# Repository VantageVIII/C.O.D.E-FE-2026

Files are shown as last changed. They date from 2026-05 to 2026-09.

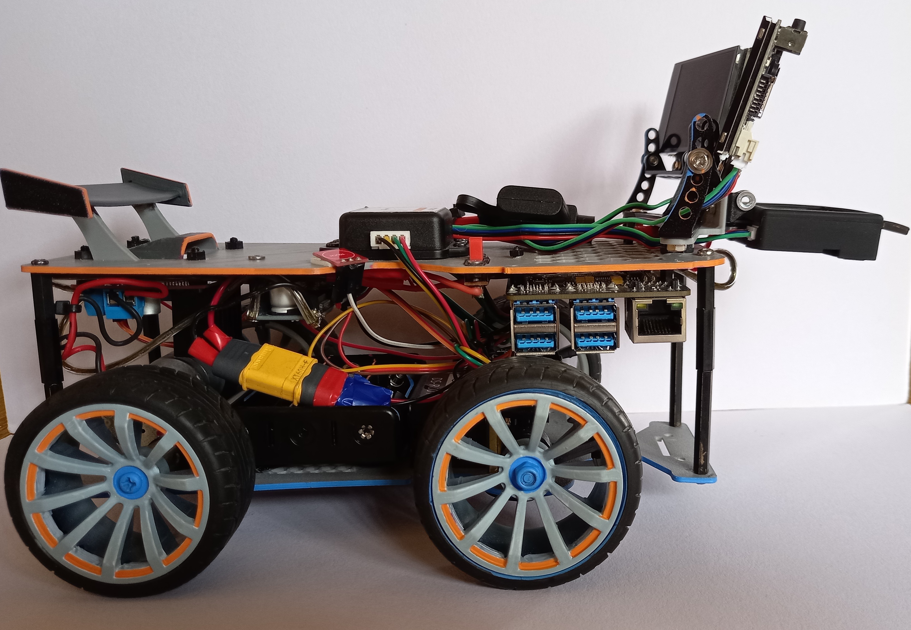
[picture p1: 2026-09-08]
media/Robot photos/Right.jpg

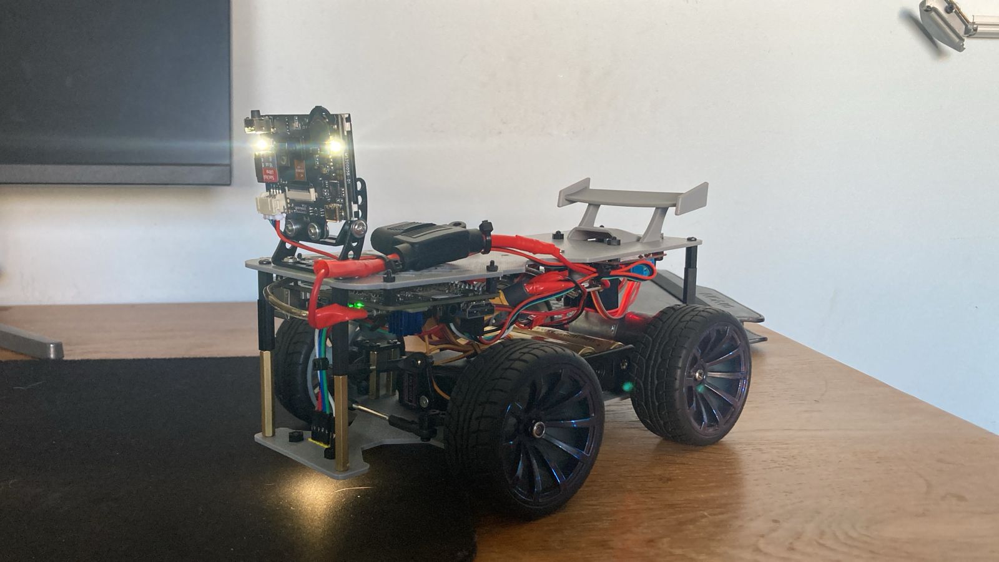
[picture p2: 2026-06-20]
media/Additional Media/Photos/WhatsApp Image 2026-05-23 at 15.05.25.jpeg

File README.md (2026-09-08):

# Team C.O.D.E. - WRO Future Engineers 2026

**Team Name:** Cognitive Operations & Digital Engineering (C.O.D.E.)

**Team Members:** Jadon Steele & Mischa Miller

**Robot Name:** MSE-6 (Alias: "Mouse")

Welcome to the official GitHub repository for Team C.O.D.E. This repository contains all the source code, 3D CAD models, documentation, and media for our autonomous vehicle designed for the World Robot Olympiad (WRO) Future Engineers 2026 competition. 

Our engineering philosophy this season focuses on **simplification and consistency**. By upgrading to an RDK X5 edge computer and a tri-camera HuskyLens vision system, we shifted the complexity from hardware sensor arrays to software processing, resulting in a highly reliable, reproducible autonomous system.

---

## 1. Repository Structure

Our repository is organized to ensure full reproducibility for any team wishing to recreate the MSE-6:

* `/Codes/`: Contains all software required to run the robot.
  * `/Base Codes/`: Contains low-level hardware interfacing scripts (e.g., pin definitions, bit-bashing logic, motor controller initialization).
  * `/Main Codes/`: Contains the high-level logic, including the finite state machine, mapping algorithms, and obstacle avoidance logic for the competition runs.
  * `/Test Codes/`: Contains isolated scripts used during development to test individual components.
* `/models/`: Contains all 3D-printable `.STL` files for our custom ABS chassis, including the upper plate, lower plate, ribs, and camera mounting brackets.
* `/Documentation/`: Contains our Engineering Journal, component comparisons, color value logs, and problem-solving logs.
* `/media/`: Contains photos and videos of the robot in action, including official qualification run recordings.
* `/other/`: Contains reference materials, rulebooks, and legacy code from the 2025 season for comparative analysis.

---

## 2. Electromechanical Components & Hardware Architecture

The MSE-6 is built using carefully selected commercial off-the-shelf components combined with a custom-fabricated chassis.

### Main Controller
* **RDK X5 SBC:** The brain of our robot. Featuring an octa-core ARM Cortex-A55 processor, 8 GB of LPDDR4 memory, and a 10 TOPS NPU (Neural Processing Unit). We selected the RDK X5 over alternatives because of its superior AI capabilities, which are essential for processing three simultaneous camera feeds. 

### Vision & Sensor System
* **3x HuskyLens V1 AI Cameras:** We utilize a tri-camera setup. One camera faces downward to read mat colors. Two forward-facing cameras are angled to provide a combined 120° field of view, detecting track boundaries and traffic pillars without blind spots.
* **DFRobot 6-Axis Accelerometer/Gyro:** Mounted precisely on the chassis center axis. This provides crucial heading data to maintain perfectly straight trajectories between turns.

### Actuation & Movement
* **Drive Motor:** A 12V 250 RPM Planetary DC motor. We opted for a high-torque ratio rather than a high-speed ratio. Because our code relies on GPIO bit-bashing for motor control, a torque-oriented layout allows for much smoother, less twitchy movement.
* **Steering:** A DFRobot DS-R001 6Kg Clutch Servo. The internal clutch mechanism is a critical reliability upgrade—if the robot collides with a wall, the clutch slips instead of stripping the servo gears.
* **Motor Driver:** L298N Dual H-Bridge.

### Power System
* **Battery:** 3S1P 18650 Lithium-ion pack (11.1V nominal). 
* **Power Regulation:** The 11.1V line runs into an XL4015 Buck Converter which steps the voltage down to a stable 5V. From the buck converter, the 5V line passes through a **5A inline blade fuse** before routing to the RDK X5 and logic components. This specific topology ensures that our 5V circuit is strictly protected from drawing more than the buck converter's maximum rating if a short occurs.

---

## 3. Step-by-Step Build & Assembly Guide

### Mechanical Assembly
1. **Print the Chassis:** Navigate to the `/models/` directory and 3D print the upper and lower chassis plates using ABS filament. ABS is required due to the operating temperatures of the RDK X5.
2. **Mount the Drivetrain:** Secure the 12V Planetary DC motor to the rear motor bracket of the lower chassis. Attach the rear solid axle and wheels.
3. **Install the Steering System:** Mount the DFRobot 6Kg Clutch Servo to the front of the lower chassis. Connect the steering linkage to the front hubs.
4. **Assemble the Tiers:** Use the provided nylon spacers to mount the upper chassis plate above the lower plate.
5. **Mount the Sensors:** Attach the custom 3-camera bracket to the upper chassis. Angle the forward cameras outwards at 15° each from the center line. 

### Electrical Wiring & Integration

Wiring Diagram

1. **Power Routing:** Connect the 3S1P battery to the XL4015 Buck Converter. Route the 5V output of the buck converter through the 5A inline fuse.
2. **Logic Power:** Connect the output of the 5A fuse to the RDK X5 power input pins. Route a parallel 12V line directly from the battery to the L298N motor driver.
3. **Motor Control:** Connect the RDK X5 GPIO pins to the IN1, IN2, and ENA pins on the L298N. 
4. **Sensor Comms:** Connect the three HuskyLens cameras and the DFRobot Gyro to the I2C/UART interface pins on the RDK X5. 

---

## 4. Software Architecture & Game Strategy

Our software is written in Python and runs on the RDK OS. We utilize a highly optimized Finite State Machine (FSM) to separate our strategies for Round 1 (Open Challenge) and Round 2 (Obstacle Challenge).

### Round 1: Open Challenge Strategy

[View Round 1 Flowchart (PDF)](./Documentation/flowcharts/Round%201%20Flowchart.pdf)

In Round 1, there are no traffic pillars, so our goal is maximum speed and efficiency.
1. **Orientation Logic:** The downward-facing camera scans the mat to identify the starting color (blue or orange), determining if the robot must travel clockwise or counterclockwise.
2. **Heading & Execution:** The robot relies entirely on the DFRobot Gyro for its heading. It is programmed to hug the **outer wall** as closely as possible, allowing for a wider turning radius and maximizing our top speed while remaining stable.

### Round 2: Obstacle Challenge Strategy

[View Round 2 Flowchart (PDF)](./Documentation/flowcharts/Round%202%20Flowchart.pdf)

In Round 2, the robot must obey the red and green traffic pillars. To guarantee reliability, we split the logic between a "Mapping Lap" and "Execution Laps".
1. **Orientation Logic:** Similar to Round 1, the downward camera sets the initial orientation.
2. **Lap 1 (Corner Mapping & Evaluation):** The robot drives forward using gyro heading. Crucially, the robot is programmed to **stop** at the start of a corner turn. It uses the forward-facing HuskyLens to evaluate the traffic pillar situated at the corner. Based on the pillar's color and the robot's current orientation (CW/CCW), the algorithm determines if it needs to execute a **"narrow"** or **"sharp"** turn.
3. **Memory Storage:** The robot saves this specific corner turn type (narrow or sharp) into an array sequence.
4. **Laps 2 & 3 (Corner Execution & Real-Time Avoidance):** For the remaining two laps, the robot utilizes a hybrid approach:
   * **Corner Turns (Memory):** When the robot reaches the corners, it does not rely on the cameras. Instead, it reads the saved turn sequence (narrow or sharp) from memory and executes it "blindly." This is a vital engineering decision: by navigating corners purely from memory on Laps 2 and 3, the robot mitigates the risk of missing a pillar or executing a wrong turn due to minor offsets or imperfections that accumulate over the run.
   * **Straightaway Pillars (Real-Time):** For pillars located on the straight sides of the track, the robot actively uses the forward HuskyLens cameras to detect and avoid them in real-time, safely shifting lanes as necessary.

---

## 5. Installation & Execution Guide

### To run the software on a fresh RDK X5 setup:
**Application Download List:**
* [RDK Studio](https://d-robotics.github.io/rdk_x_doc/en/RDK/)
* [Thonny](https://thonny.org/)
* [Github Desktop](https://desktop.github.com/download/)
* [Google Antigravity](https://antigravity.google/download)

1. **Flash the OS:** Download the official RDK Studio and flash RDK OS Linux onto the RDK X5.

2. **Install Dependencies:** Ensure Python 3 is installed. Then install the required libraries:
   ```bash
   pip install matplotlib numpy smbus smbus2
   sudo apt-get install i2c-tools
   ```

3. **Clone the Repository:**
   ```bash
   git clone https://github.com/VantageVIII/C.O.D.E-FE-2026.git
   cd C.O.D.E-FE-2026
   ```

4. **Run the Code:** Navigate to the Main Codes directory and execute the competition script:
   ```bash
   cd Codes/Main\ Codes/
   python3 main_run.py
   ```

---

## 6. License and Credits
Designed and programmed by Team C.O.D.E. (Jadon Steele & Mischa Miller) for the WRO Future Engineers 2026 Season. Special thanks to HelderBerg Robotics Club for their continued support, and Prints by Paul for 3D manufacturing assistance.

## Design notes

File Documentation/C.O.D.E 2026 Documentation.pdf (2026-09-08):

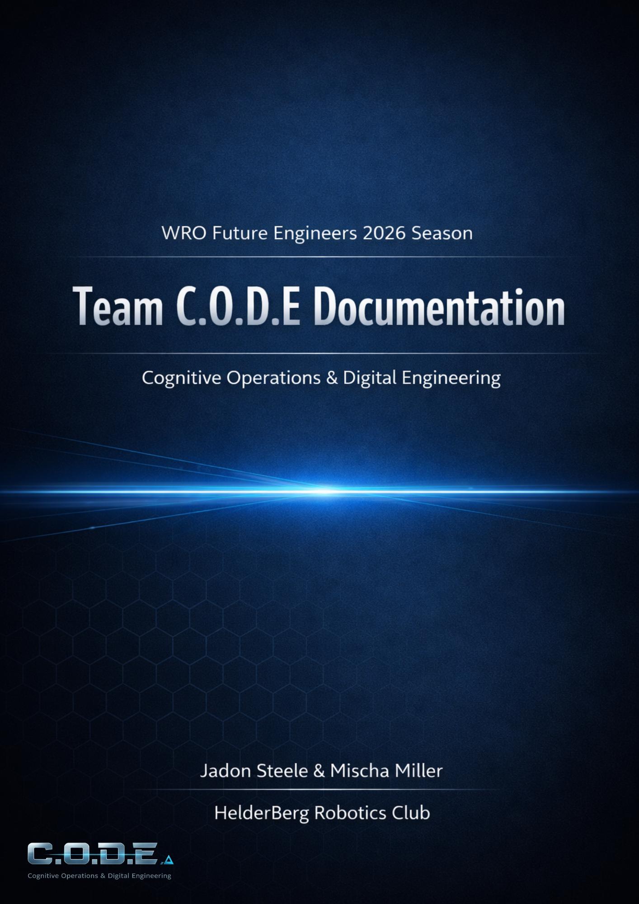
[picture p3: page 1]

# Index

### 1 Introduction

### 1.1 Team Introduction

### 1.2 Robot Introduction

### 2 Robot Hardware

### 2.1 Interfaces

### 2.1.1 UART

### 2.1.2 I2C

### 2.2 Electronics

### 2.2.1 RDK X5

- Libraries
- Reason

### 2.2.2 Power

- Batteries
- Blade 5A Fuse & Fuse Holder
- Buck Converter

### 2.2.3 Sensors

- Huskylens V1
- Gyro (DFRobot 6-Axis Accelerometer)
- Capacitive Touch Sensor

### 2.2.4 Movement

- DS-R001 – Clutch Servo Motor
- DC Motor
- L298N

### 2.2.5 Wiring Diagram

### 2.3 Chassis/Other

### 3 Software and Strategy

### 3.1 Open challenge Strategy

### 3.2 Obstacle challenge Strategy

### 3.3 Calibration

### 3.4 Open challenge flowchart

### 3.5 Obstacle challenge flowchart

### 4 Robot Journey

### 4.1 Changes from 2025 Season

### 4.2 Monthly Logs

- January Log
- February Log
- March Log
- April Log
- May Log
- June Log
- July Log
- August Log

# Team Introduction: Team C.O.D.E

We are Team C.O.D.E, (https://github.com/VantageVIII/C.O.D.E-FE-2026.git) a two-person team competing in the WRO Future Engineers category. We first met during last season's FTC competition and quickly discovered that we shared a passion for robotics, engineering, and programming. Since then, we've worked together to design, build, and improve an autonomous vehicle that can tackle the challenges of the Future Engineers competition.

## Meet the Team:

### Mischa Miller

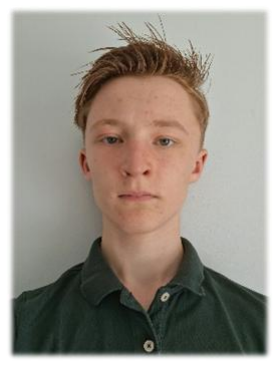
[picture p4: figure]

Role: Strategy & Quality Assurance Lead

Mischa is responsible for planning, testing, and keeping the project organised. He manages our engineering journal, tracks our progress, and helps make sure every change we make is tested and documented. His focus is on making sure the team stays on schedule and that our robot performs consistently and reliably.

### Jadon Steele

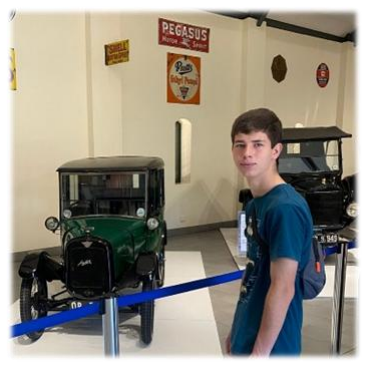
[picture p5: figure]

Role: Lead Engineer & Programmer

Jadon leads the design and development of our robot. He is responsible for programming the autonomous system, integrating sensors, and improving the mechanical design. Drawing on several years of robotics competition experience, he enjoys solving technical problems and finding ways to make our robot more accurate and reliable.

## Our Goal:

Our goal is to represent South Africa for the WRO International Finals. To get there, we're focused on building a reliable autonomous vehicle that can consistently complete every challenge in the Future Engineers competition. We know that success comes through careful planning, regular testing, and continuously improving our design. No matter the result, we hope to learn new skills, gain valuable experience, and represent our team to the best of our ability.

# Robot Introduction

Meet the WRO FE MSE-6 (also known as Mouse), our autonomous vehicle designed specifically for the WRO Future Engineers competition. Every component was selected to maximise reliability, performance, and consistency during autonomous operation.

The robot uses a tri-camera HuskyLens AI setup. Two cameras face forward, each with a 60° field of view, giving wide coverage of the competition field. A third camera faces downward toward the mat, replacing the original colour sensor.

- Forward cameras:
- Detect lane markings, pillars, and obstacles.
- Provide a combined forward view that improves navigation accuracy and reduces blind spots.
- Downward camera:
- Captures mat colours and features with greater precision than the previous colour sensor.
- Operates at higher speed, enabling faster runs without sacrificing detection reliability.
- Supplies data for mapping and route planning, feeding into the robot’s ID set → route set pipeline.

Advantages of the Tri-Camera System

- Higher accuracy: Downward HuskyLens delivers richer colour and pattern recognition.
- Speed optimisation: Robot maintains faster lap times while keeping detection consistent.
- Consistency: Reduces twitching and misreads, ensuring smoother lap execution.

Processing the large amount of data from the cameras requires a powerful onboard computer. For this reason, we chose the RDK X5, which features an octa-core ARM Cortex-A55 processor and 8 GB of LPDDR4 memory. This provides enough computing power to run our vision algorithms and control systems in real time, allowing the robot to operate fully autonomously.

The following sections describe the robot's mechanical design, electronics, software, and the testing process that led to the final version of the MSE-6.

For the Mechanical, electronic, and software design we tried to keep it as simple as possible

# Robot Photos:

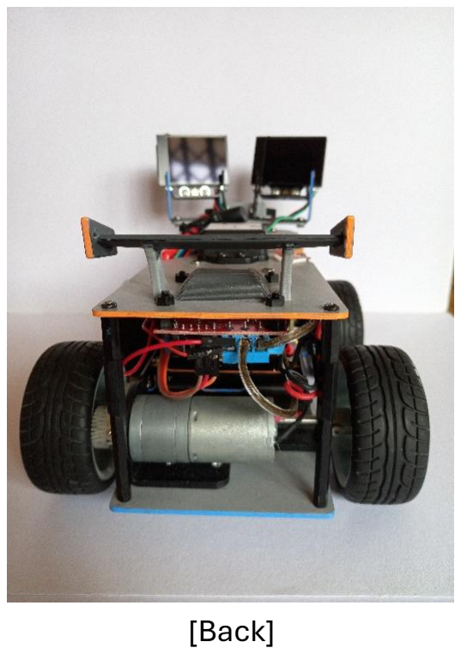
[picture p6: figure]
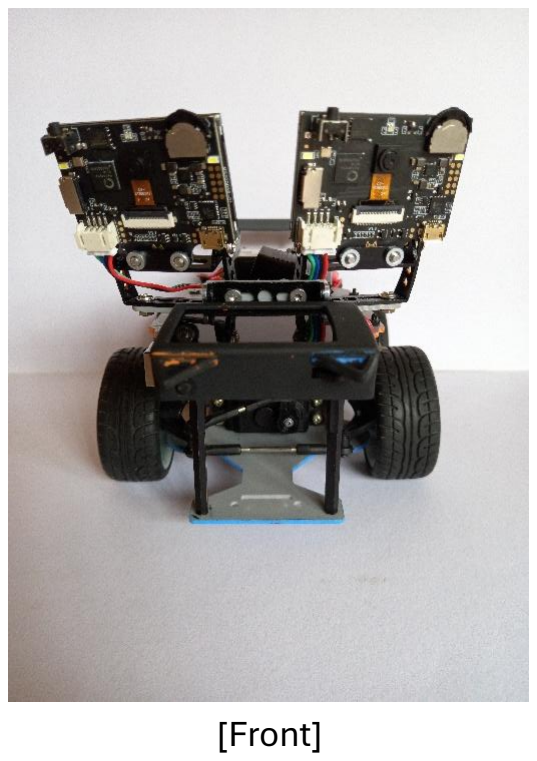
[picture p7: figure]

[Front] | [Back]

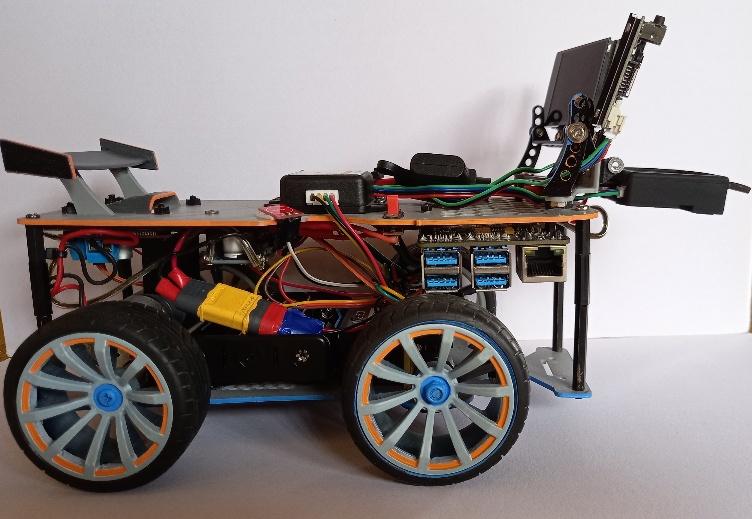
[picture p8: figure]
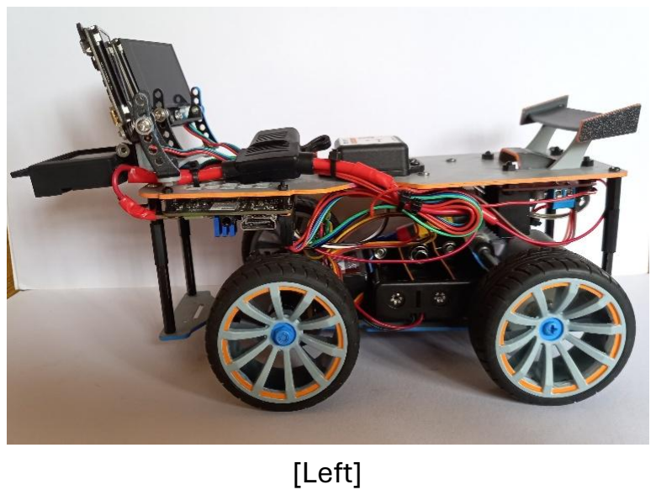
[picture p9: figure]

[Right] | [Left]

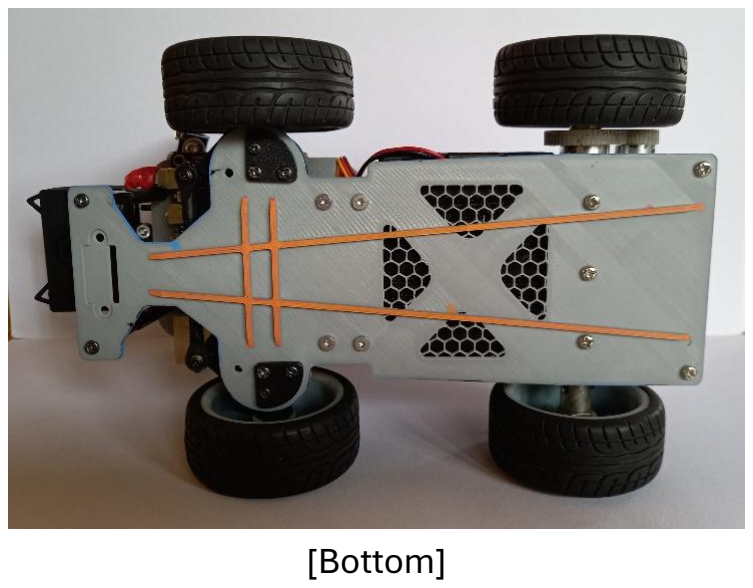
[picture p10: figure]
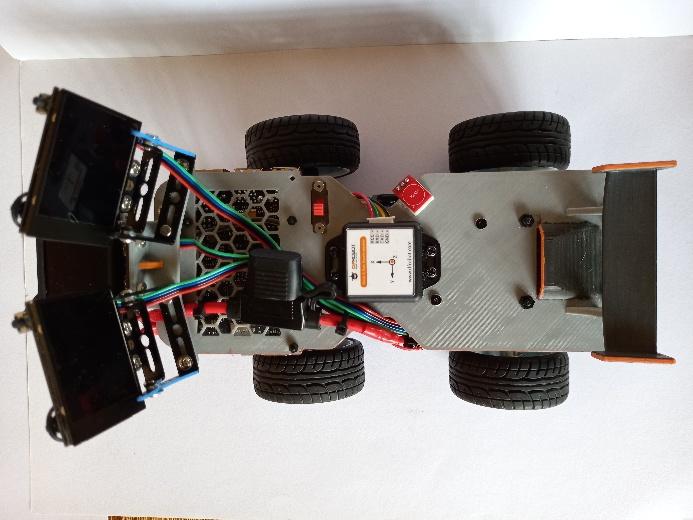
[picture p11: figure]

[Bottom] [Top]

# Robot Hardware/Specifications:

## Interfaces:

### UART:

Universal Asynchronous Receiver/Transmitter (UART)
Definition:

UART is a hardware communication protocol that enables asynchronous serial data transmission between devices. It converts parallel data from a microcontroller or computer into serial form for transmission and reconverts received serial data back into parallel form.

Key Characteristics:

- Asynchronous Communication: No shared clock signal; synchronization is achieved using start and stop bits.
- Full Duplex: Supports simultaneous transmission (TX) and reception (RX).
- Frame Structure: Data is sent in packets consisting of: • Start bit (signals beginning of data frame) • Data bits (usually 7, 8, or 9 bits) • Optional parity bit (error detection) • Stop bit(s) (signals end of frame)
Typical Parameters:
- Baud Rate: Speed of transmission (e.g., 9600, 115200 bps).
- Data Bits: Commonly 8 bits per frame.
- Parity: None, even, or odd.
- Stop Bits: 1 or 2 bits.
Applications:
- Microcontroller ↔ Sensor communication (e.g., accelerometers, GPS modules).
- Debugging and logging via serial consoles.
- Embedded systems interfacing (Arduino, Raspberry Pi, etc.).
- Peripheral connections (Bluetooth modules, GSM modems).

Hardware Interface:

- TX (Transmit): Sends data out.
- RX (Receive): Reads incoming data.
- GND: Common ground reference.
- Optional RTS/CTS lines for hardware flow control. Advantages:
- Simple and widely supported.
- Requires only two data lines (TX, RX).
- Flexible baud rate configuration.
Limitations:
- Point-to-point only (not multi-drop like RS-485).
- Limited distance and speed compared to modern protocols (e.g., USB, SPI).
- No inherent clock synchronization — requires precise baud rate matching. Components Using UART:
- 3x HUSKYLENS V1
- Gyro
_________________________________________________________________________________

I2C:

Inter-Integrated Circuit (I²C)
Definition:

I²C is a synchronous, multi-master, multi-slave, serial communication protocol developed by Philips (now NXP). It enables short-distance communication between integrated circuits using only two bidirectional lines: SDA (Serial Data) and SCL (Serial Clock).

Key Characteristics:

- Synchronous Communication: Data transfer is synchronized with a shared clock (SCL).
- Two-Wire Interface: Only SDA and SCL lines are required, plus ground.
- Multi-Device Support: Multiple masters and slaves can share the same bus.
- Addressing: Each slave device has a unique 7-bit or 10-bit address.
- Open-Drain Design: Devices pull the line low; external pull-up resistors are required. Typical Parameters:
- Clock Speed: Standard (100 kHz), Fast (400 kHz), Fast Plus (1 MHz), High-Speed (3.4 MHz).
- Data Frame Structure: • Start condition (SDA pulled low while SCL is high) • Address frame (7/10 bits + R/W bit) • ACK/NACK bit (acknowledgment from receiver) • Data frames (8 bits each, followed by ACK/NACK) • Stop condition (SDA released high while SCL is high)
Applications:
- Communication between microcontrollers and peripherals (EEPROMs, sensors, displays).
- Configuration of ICs in embedded systems.
- Power management ICs and real-time clocks.
- Consumer electronics (smartphones, TVs, cameras). Hardware Interface:
- SDA (Serial Data): Transfers data between devices.
- SCL (Serial Clock): Synchronizes data transfer.
- Pull-Up Resistors: Required on both lines to maintain logic high when idle.

Advantages:

- Simple wiring (two lines for many devices).
- Supports multiple masters and slaves.
- Well-suited for low-speed, short-distance communication. Limitations:
- Limited speed compared to SPI or UART.
- Bus capacitance restricts maximum distance and number of devices.
- Requires careful pull-up resistor sizing for reliable operation. Components Using I²C:
- TCS34725 – Colour Sensor (Removed)

### ______________________________________________________________________

## Electronics:

### RDK X5:

The RDK X5 was chosen as the main controller for the robot because it offers the best balance of AI acceleration, connectivity, and GPIO support compared to other SBCs in the comparison:
AI Acceleration:
- Equipped with a 10 TOPS BPU (Neural Processing Unit), the RDK X5 is far more capable for edge AI and robotics tasks than the Raspberry Pi 5 (limited AI acceleration) and Jetson Nano (fixed 4 GB RAM, older GPU).
Connectivity:
- Built-in Wi-Fi 6 + Bluetooth 5.4 ensures modern wireless standards, unlike the Jetson Nano which lacks onboard Wi-Fi.
GPIO & Interfaces:
- Provides 28 GPIOs with support for SPI, I²C, I²S, PWM, and UART, covering all the communication protocols needed for sensors and actuators in the robot.
Form Factor:
- Compact dimensions (85 × 56 × 20 mm) make it stackable and ideal for embedded robotics, unlike the larger Jetson Nano or LattePanda Delta 3.

Power Input:
- Runs on a simple 5V/5A USB-C supply, compatible with the robot’s buck converter and battery system.
OS Support:
- Supports Ubuntu 22.04 and RDK OS Linux, giving flexibility for robotics frameworks like ROS2.
Why Not the Others?
- Raspberry Pi 5: Excellent community support and dual 4K display, but limited AI acceleration and requires active cooling.
- Jetson Nano: Strong AI features with CUDA, but restricted by fixed 4 GB RAM and no onboard Wi-Fi.
- LattePanda Delta 3: Runs Windows/Linux with powerful x86 CPU, but higher power draw and larger form factor make it less suited for compact robotics.
Conclusion:
The RDK X5 was selected because it combines AI performance, modern connectivity, versatile GPIO support, and compact design, making it the most suitable SBC for an edge AI robotics platform.
_________________________________________________________________________________

### Power:

Battery System – 18650 Lithium Cells (3S1P Pack)

Configuration
- Type: 18650 Lithium-ion cells
- Arrangement: 3S1P (3 cells in series, 1 parallel string)
- Nominal Voltage per Cell: 3.7 V
- Capacity per Cell: ~3000 mAh (3.0 Ah)
Pack Specifications
- Nominal Voltage: Vtotal = 3 × 3.7 V = 11.1 V
- Maximum Voltage (Fully Charged): Vmax = 3 × 4.2 V = 12.6 V
- Total Capacity: Ctotal = 3.0 Ah
- Energy Stored: E = 11.1 V × 3.0 Ah ≈ 33.3 Wh

Current Output
- Continuous Current: Depends on the discharge rating of the cells. • Standard 18650 cells: ~5–10 A continuous • High-drain 18650 cells (used in power tools, e-bikes, robotics): 15–20 A continuous, sometimes higher
- Peak Current: Short bursts can exceed 20 A depending on cell quality.
- Pack Limitation: Since this is a 3S1P pack, the current capability is limited to what a single cell can provide (no parallel strings to share load).
Practical Notes
- Runtime per pack: ~45 minutes under typical robot load.
- Multiple packs are rotated to ensure a fully charged set is always available.
- Inline 5 A fuse in combination with the Buck Converter is used for protection of the board, but the cells themselves can deliver much higher current. _________________________________________________________________________________________ Buck Converter – 5V/5A (XL4015)

Part Description
The XL4015 is used to step down our 11.1V battery to a stable 5V to safely power the RDK X5 and HuskyLenses. We specifically required a regulator with a 5A limit because our combined AI processing and vision system draws a peak of ~4.19A. We chose this switching buck converter over a linear regulator because of its high conversion efficiency (up to 96%), ensuring that power isn't wasted as heat during our 3-lap runs.
Quick Specifications
- Input Voltage: 4 – 38 V
- Output Voltage: 1.25 – 32 V (adjustable)
- Output Current: 5 A (max; recommended ≤ 4.5 A)
- Output Power: 75 W
- Working Temperature: –40 to +85 °C
- Working Frequency: 180 kHz
- Conversion Efficiency: up to 96% (depends on input/output voltage, current, and voltage drop)
- Load Regulation Rate: S(I) ≤ 0.8%
- Voltage Adjustment Rate: S(U) ≤ 0.8%
- Protection: Short-circuit protection, Over-temperature protection
- Dimensions: 54 × 23 × 18 mm
- Net Weight: 13 g

Fuse – 5A Blade Type

Part Description
The 5A blade fuse is a critical safety mechanism for our robot's logic circuit. We installed it directly after the XL4015 Buck Converter on the 5V line before the power reaches the RDK X5 and HuskyLenses. We explicitly chose a 5A rating because our peak logic current draw is calculated at ~4.19A. This provides enough headroom for AI processing spikes, but guarantees that if a short circuit occurs, the fuse will blow before our sensitive logic components melt or the buck converter exceeds its maximum rating.
Quick Specifications
- Rated Voltage: 32 V
- Rated Current: 5 A
- Fuse Colour: Clear Orange
- Dimensions: 19 × 19 × 5 mm
- Net Weight: 13 g

Fuse Holder – Inline Blade Type
Part Description
This inline holder integrates the 5A blade fuse into our main wiring harness. We chose an inline automotive-style holder because it provides a highly secure, vibration-proof connection during high-speed runs and sharp 45° turns. Furthermore, its simple plug-and-play design means that if we blow a fuse during a competition round, we can physically replace it in the pits in under 10 seconds without needing to solder or rewire the chassis.
Quick Specifications
- Max Voltage: 48 V
- Max Current Rating: 32 A (Peak 40 A)
- Fuse Seat Size: 40 × 35 × 24 mm
- Net Weight: 23 g

### Sensors:

Huskylens V1 – AI Vision Sensor:
Part Description

The HuskyLens is the core of our robot's vision system. We transitioned from a 2025 sensor array (Time-of-Flight + traditional colour sensors) to a custom Tri-Camera HuskyLens setup. One camera faces downward for high-speed mat colour recognition (track mapping), while two face forward, angled to provide a massive 120° combined field of view to detect traffic pillars on corners. We chose the HuskyLens specifically to offload processing from our main computer. Instead of the RDK X5 analysing raw video pixels, the built-in Kendryte K210 AI chip on the HuskyLens handles the heavy object-recognition math, sending only lightweight coordinate data to the RDK X5 via I2C/UART. This brilliant division of labour drops our system latency and drastically improves lap times.
Quick Specifications
- Processor: Kendryte K210
- Image Sensor: OV2640 (2.0 Megapixel Camera)
- Supply Voltage: 3.3 – 5.0 V
- Current Consumption (Typical): 320 mA @ 3.3 V, 230 mA @ 5.0 V (face recognition mode; 80% backlight brightness; fill light off)
- Connection Interface: UART, I²C
- Display: 2.0-inch IPS screen, 320 × 240 resolution
- Built-in Algorithms: Face Recognition, Object Tracking, Object Recognition, Line Tracking, Colour Recognition, Tag Recognition
- Dimensions: 52 × 44.5 mm

Gyro – DFRobot 6 axis accelerometer:
Part Description

The gyro is the cornerstone of our robot's straight-line navigation. In Round 1, the robot relies entirely on this sensor's heading data to hug the outer wall of the track at high speeds. We specifically selected this DFRobot module over cheaper alternatives (like the standard MPU6050) because it features an integrated microprocessor running advanced Kalman filter algorithms. This means the sensor internally cleans up its own noise and calculates an accurate attitude angle before sending data to the RDK X5. By offloading this math, we save valuable CPU cycles on the RDK X5 for processing our three camera streams. During testing, we applied a deliberate 10° software offset to the gyro's zero-heading, which biases the robot slightly inward during runs to prevent accidental outer-wall clipping.

Quick Spec

- Voltage: 3.3V~5V
- Current: <40mA
- Measuring Dimension: acceleration: 3D; angular velocity: 3D; attitude angle: 3D
- Range: acceleration: ±2/4/8/16g(optional); angular velocity: ±250/500/1000/2000°/s (Optional); attitude angle: ±180°
- Dimensions: 51.3 x 36 x 10mm
- Net Weight: 18g

TTP223 Capacitive Touch Sensor:
Part Description

The WRO rulebook requires a strict, physical start procedure to initiate the autonomous run. We utilize the TTP223 as our main start trigger. We chose a capacitive touch sensor over a traditional mechanical push-button to solve a critical software issue: "signal bounce." Mechanical switches physically bounce when pressed, sending dozens of rapid ON/OFF signals in a matter of milliseconds, which can accidentally multi-trigger or crash our software's bit-bashing loop. The TTP223 IC completely eliminates this issue, delivering a single, digitally clean, and debounced signal that guarantees a flawless launch off the starting line every single time. Quick Spec

- IC: TTP223 Touch Pad Detector
- Input Voltage: 2.0V – 5.5V DC
- Standby Current: < 10µA
- Response Time: ~60ms (Fast Mode) / ~220ms (Low Power Mode @3V)
- Touch Detection Range: 0 – 10mm (depending on surface material)
- Output Modes: Momentary or Latching / Active-High or Active-Low selectable
- Sensitivity Adjustment: External capacitance (0–50pF)
- Auto Calibration: Recalibrates every 4 seconds (no touch)
- Operating Temperature: –40°C to +85°C
- Dimensions: 15mm × 11mm × 2.5mm

### Movement

DS-R001 – 6Kg Clutch Servo Motor:
Part Description

This servo acts as our front-wheel steering actuator. We upgraded to this clutch servo after our original MG996R burned out during testing. The built-in clutch mechanism is vital for our robot's reliability: if the robot crashes into a track wall, the clutch slips at 6kg of torque rather than stripping the internal gears or stressing our 3D-printed chassis linkage. This gives us much smoother and safer steering.
Quick Spec
- Operating Voltage: 4.8-6V DC
- Static Current: ≤10mA @ 6.0V
- Current (at no load): ≤60mA @6.0V
- Current (at stopped): ≤1.65A @6.0V
- Rated Torque: ≥4.4kg·cm @6.0V
- Stall Torque: 6kg.cm @6.0V
- Operating Travel: 300°±10°
- Pulse Width Range: 500~2500μs
- Communication Mode: PWM

L298N – Dual H-Bridge Motor Driver:
Part Description

The L298N serves as the critical link between our RDK X5 logic controller and our 12V drive motor. Unlike our sensors which run off the 5V buck converter, the L298N is wired directly to the 11.1V battery line to provide maximum unchecked voltage to the drivetrain. We chose this specific H-Bridge because of its massive onboard heat sink and high power-dissipation rating (25W). Because we use a software "bit-bashing" control method rather than hardware PWM, the control signals sent to the driver's ENA pin can cause rapid switching states; the L298N's robust thermal design easily absorbs the resulting heat without failing during long competition rounds

Quick Spec

- Dual H-Bridge Driver
- IC: L298N (ST),/li>
- Logic voltage: 5VDC (has onboard 5V regulator if you would like to power from 12V)
- Drive voltage: 5-35VDC
- Drive current: 2A (MAX single bridge)
- Dimensions: 43 x 57mm

DC Motor – 250 RPM Planetary
Part Description
This planetary DC motor powers our solid-axle rear-wheel drive. Selecting the right motor was one of our most important design trade-offs. We intentionally avoided high-speed motors in favour of this torque-oriented 250 RPM model. Because our RDK X5 utilizes bit-bashing for motor control, a highly geared, torque-heavy motor allows for much smoother and more predictable acceleration, eliminating the sudden "twitching" we experienced with faster motors. Additionally, its stall torque of 3.86 kg.cm easily overcomes the static friction and inertia of our fully loaded chassis, while the internal metal planetary gears prevent the transmission from stripping during emergency braking or rapid direction changes.
Quick Spec
- Operating Voltage: 12V (6-18V range)
- Current (no load): 100mA
- Current (load): 330mA
- Stall Current: 1500mA
- Speed (no load @ 12V): 250rpm
- Speed (load @ 12V): 175rpm
- Load Torque: 1.1kg.cm (0.107 Nm)
- Stall Torque: 3.86kg.cm (0.378 Nm)
- Gear Ratio: 1:35
- Shaft Length: 8mm
- Shaft Diameter: 4mm
- Shaft Style: D-Shape
- Dimensions: 52.6 x 24.4mm (diameter)
- Weight: 87g

### Wiring Diagram

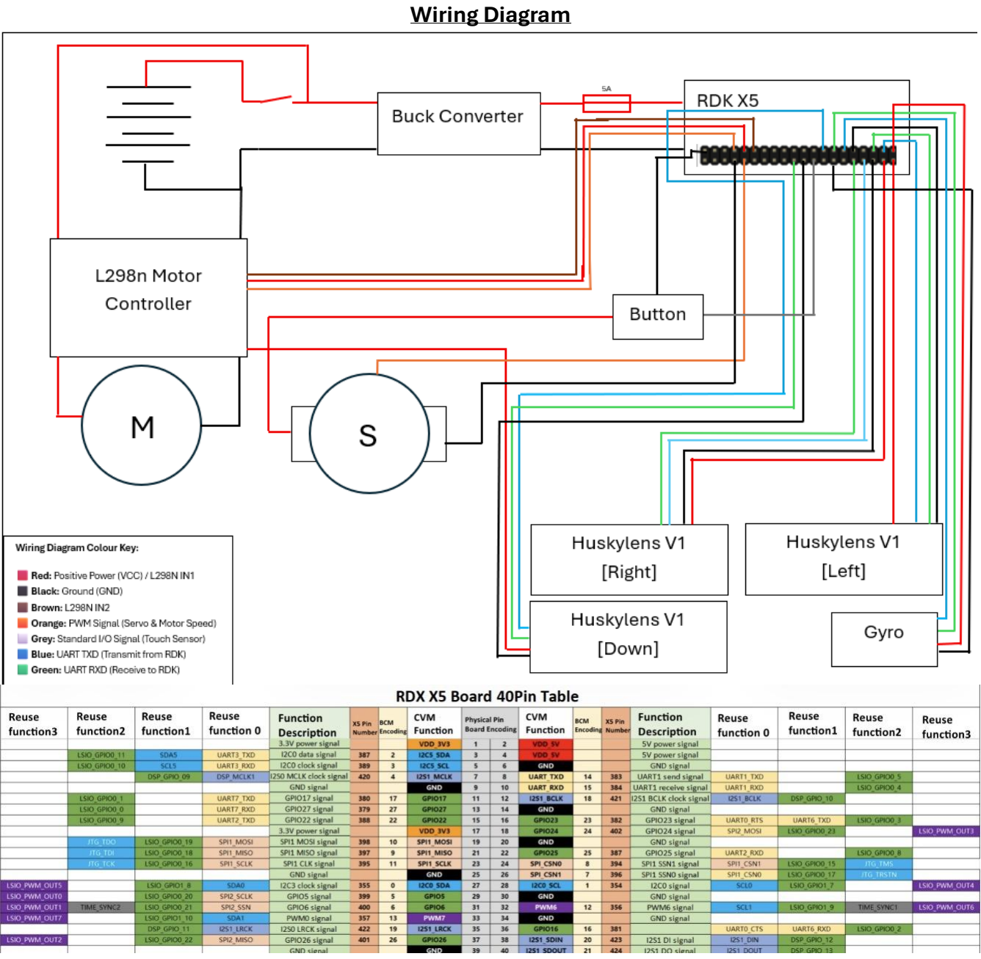
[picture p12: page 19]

## Chassis/Other

Our chassis is primarily 3D-printed from Creality ABS filament, manufactured by Prints by Paul. ABS was selected over PLA or PETG because of its thermal resistance and rigidity — ensuring the frame does not flex under load and can withstand the heat generated by the RDK X5 SBC and the L298N H-Bridge motor controller.
Material Choices
- ABS (Chassis plates):
- High rigidity prevents flexing under torque.
- Superior thermal tolerance compared to PLA, reducing risk of warping near heat-intensive components.
- Metal (Motor brackets):
- Supplied with the starter kit.
- Used where motors apply direct mechanical load, ensuring durability and preventing bracket deformation.
Structural Design
- Two-plate layout:
- Plates separated by spacers for modularity and airflow.
- Lower chassis: houses the servo motor, DC motor, and battery pack.
- Upper chassis: houses the RDK X5, L298N motor controller, 5A buck converter, 3x Huskylens V1 camera, capacitive touch sensor (button), and DFRobot 6-axis gyro.
- Rib reinforcement:
- Bottom chassis includes ribs to distribute stress and resist cracking.
- Provides additional strength against torque forces from the DC motor and steering servo.
- Airflow optimization:
- Designed with channels and spacing to direct airflow to thermal-intensive components.
- Prevents overheating during extended runs.

Drivetrain & Geometry:

- Configuration: Solid-axle rear-wheel drive, with front-wheel steering.
- Wheelbase: 115 mm (11.5 cm).
- Steering angle: Up to 50°, yielding a 40 cm turning radius.
- Wheel dimensions: 25 mm width, 65 mm diameter.
- Track width: 140 mm overall.

Functional & Aesthetic Features:

- Air scoop: positioned to “cool” the motor controller, while also adding a distinctive look.
- Wing handle: doubles as a carrying grip, especially useful during runaway test moments.
- Personal touches: break away from the typical cube-like or brick-like robot designs, giving the chassis personality and recognizability.

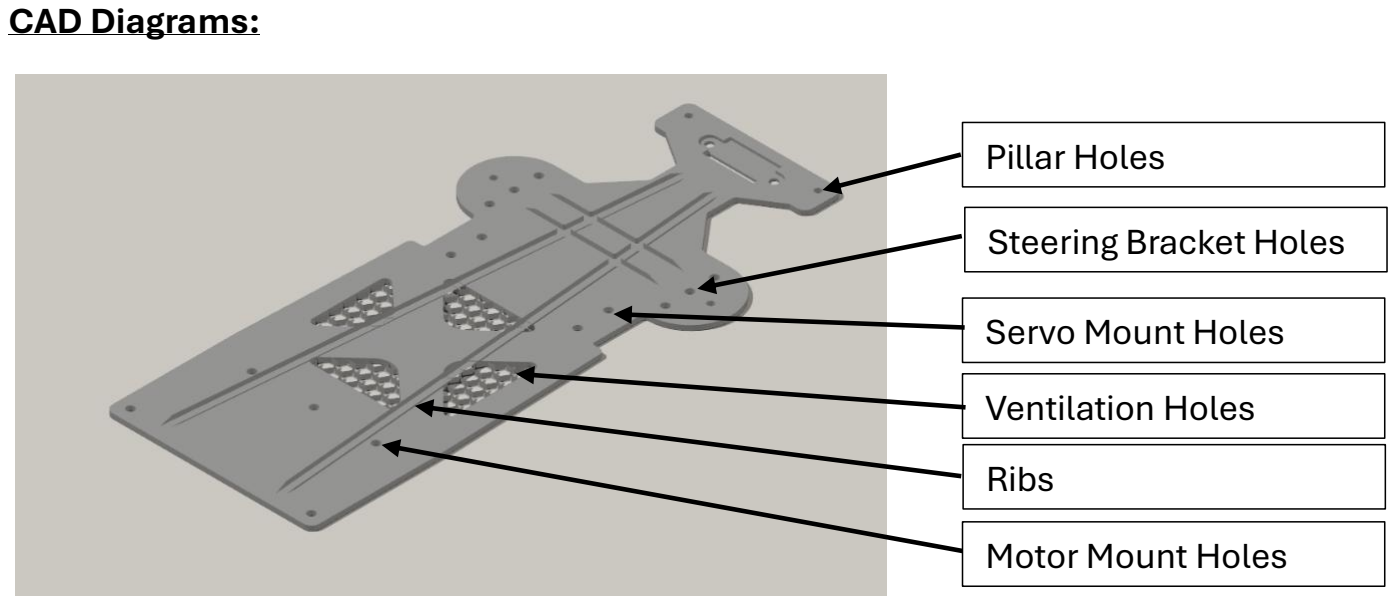
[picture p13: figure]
CAD Diagrams:; Ribs; Steering Bracket Holes; Ventilation Holes; Pillar Holes; Motor Mount Holes; Servo Mount Holes
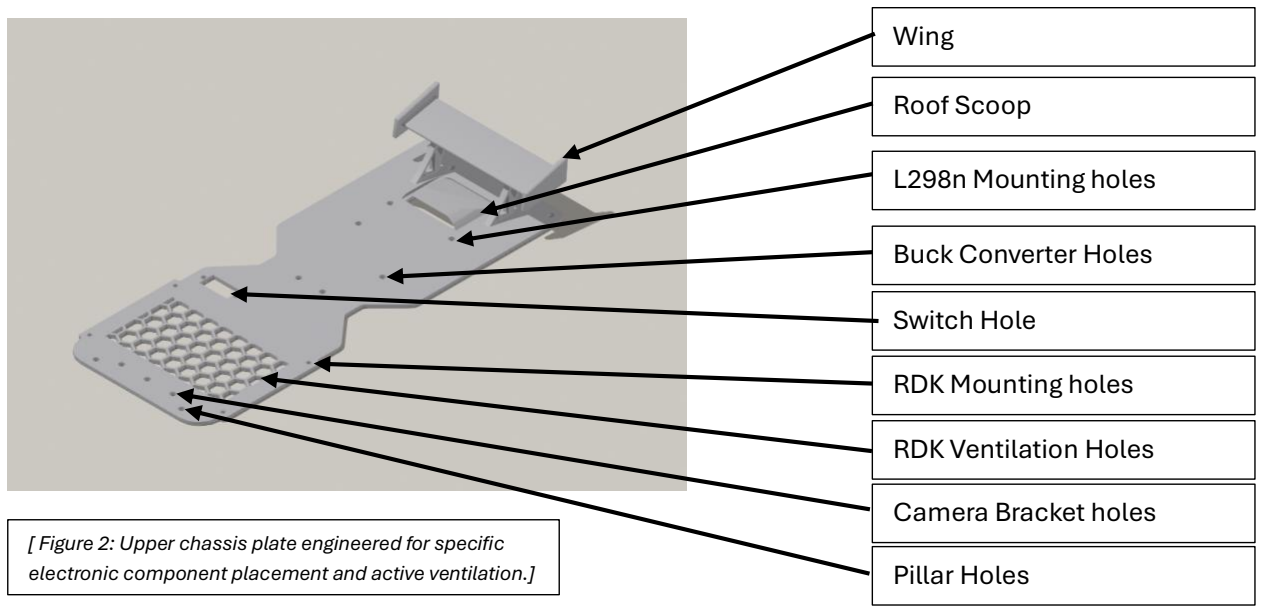
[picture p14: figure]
Pillar Holes; RDK Mounting holes; Buck Converter Holes; L298n Mounting holes; Wing; RDK Ventilation Holes; Camera Bracket holes; Roof Scoop; Switch Hole

Camera mounting holes

[ Figure 2: Upper chassis plate engineered for specific electronic component placement and active ventilation.]

[Figure 1: Lower chassis plate highlighting longitudinal structural ribs and motor mounts.]

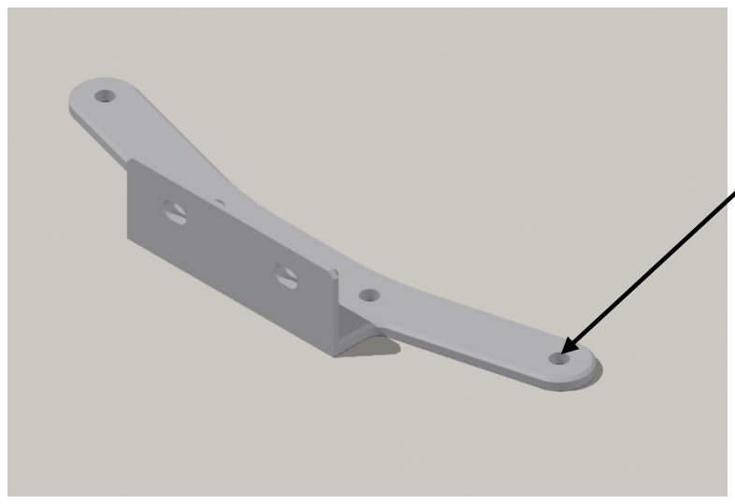
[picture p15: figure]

[Figure 3: Custom tri-camera HuskyLens mounting bracket.]

# Software & Strategy

### Round 1: Open Challenge Strategy

In Round 1, there are no traffic pillars, so our goal is maximum speed and efficiency.
1 - Orientation Logic:
The downward-facing camera scans the mat to identify the starting colour (blue or orange), determining if the robot must travel clockwise or counterclockwise.
2 - Heading & Execution:
The robot relies entirely on the DFRobot Gyro for its heading. It is programmed to hug the outer wall as closely as possible, allowing for a wider turning radius and maximizing our top speed while remaining stable.

### Round 2: Obstacle Challenge Strategy

In Round 2, the robot must obey the red and green traffic pillars. To guarantee reliability, we split the logic between a "Mapping Lap" and "Execution Laps".
1 - Orientation Logic:
Similar to Round 1, the downward camera sets the initial orientation.
2. Lap 1 (Corner Mapping & Evaluation):
The robot drives forward using gyro heading. Crucially, the robot is programmed to stop at the start of a corner turn. It uses the forward-facing HuskyLens to evaluate the traffic pillar situated at the corner. Based on the pillar's colour and the robot's current orientation (CW/CCW), the algorithm determines if it needs to execute a "narrow" or "sharp" turn.
3 - Memory Storage:
The robot saves this specific corner turn type (narrow or sharp) into an array sequence.
4 - Laps 2 & 3 (Corner Execution & Real-Time Avoidance):
For the remaining two laps, the robot utilizes a hybrid approach:
Corner Turns (Memory): When the robot reaches the corners, it does not rely on the cameras. Instead, it reads the saved turn sequence (narrow or sharp) from memory and executes it "blindly." This is a vital engineering decision: by navigating corners purely from memory on Laps 2 and 3, the robot mitigates the risk of missing a pillar or executing a wrong turn due to minor offsets or imperfections that accumulate over the run.
Straightaway Pillars (Real-Time): For pillars located on the straight sides of the track, the robot actively uses the forward HuskyLens cameras to detect and avoid them in real-time, safely shifting lanes as necessary.

### Calibration

Venue lighting is the biggest variable in computer vision. On the morning of the competition, we run a pre-flight check to verify if our HuskyLens AI cameras recognize the track elements under the new ambient lighting. If there are misreads, we execute a manual re-training protocol using the cameras' built-in physical 'Learn' button. All cameras operate in "Colour Recognition" mode. For the downward-facing camera, we clear the memory and train ID 1 for the Blue line and ID 2 for the Orange line. For the forward-facing cameras, we train multiple IDs per colour to account for shadows and glare: Green pillars are mapped to IDs 1, 2, and 6, while Red pillars are
mapped to IDs 3, 4, and 5. Finally, the Magenta parking zone is mapped to ID 7.

### Round 1 Flowchart

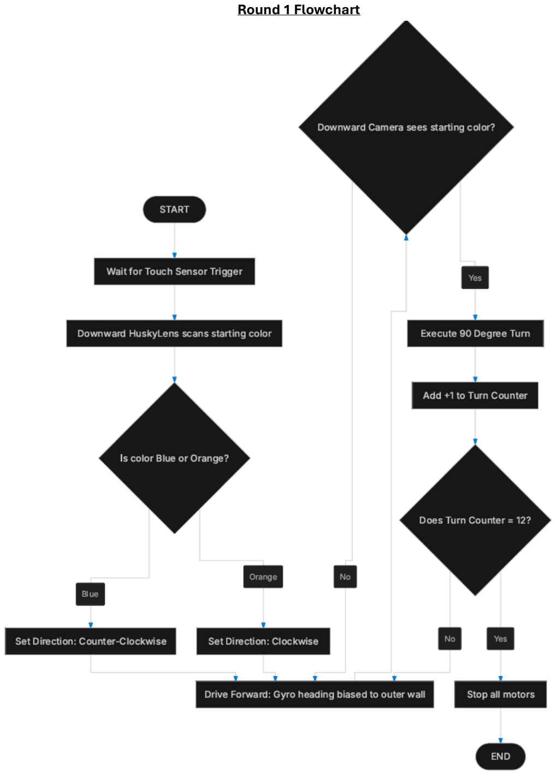
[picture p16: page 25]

### Round 2 Flowchart

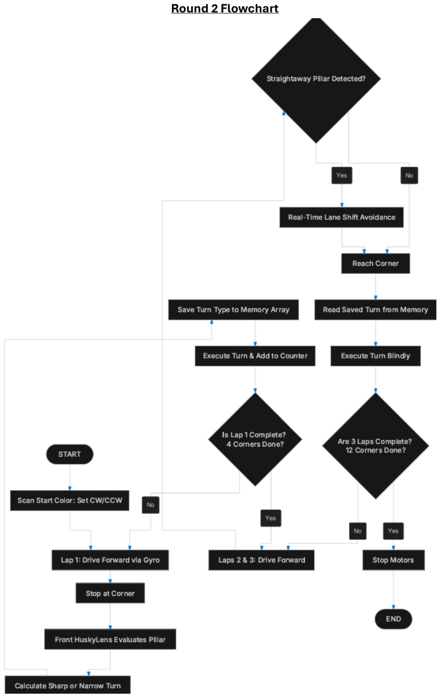
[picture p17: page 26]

# Robot Journey

## Changes from 2025 Season:

Main Controller

- 2025: Raspberry Pi 4 4Gb
- 2026: RDK X5 SBC (octa-core ARM Cortex-A55, 8 GB LPDDR4, 10 TOPS NPU, built-in Wi-Fi 6 + Bluetooth 5.4).
- Reason for change: Higher AI performance, modern connectivity, compact form factor, better GPIO support.
Vision System
- 2025: Single Raspberry Pi Camera Module 3 (front-mounted, wide FOV).
- 2026: Tri-camera HuskyLens AI setup (two forward-facing, one downward replacing colour sensor).
- Reason for change: Downward HuskyLens provides faster, more accurate mat colour/pattern recognition; forward HuskyLens improves obstacle and lane detection. Sensors
- 2025:
- 5× VL53L0X time-of-flight sensors (front + sides).
- TCS34725 colour sensor (underside).
- 2026:
- Huskylens V1 AI cameras (3 units).
- DFRobot 6-axis gyro/accelerometer.
- Capacitive touch sensor (button input).
- Reason for change: Simplified sensor suite, replaced colour sensor with downward HuskyLens for speed and accuracy, added gyro for orientation stability.
Movement & Steering
- 2025: MG996R servo motor (front steering), 250 RPM planetary DC motor, L298N motor controller.
- 2026: DS-R001 6 kg clutch servo (front steering), 250 RPM planetary DC motor, L298N motor controller.

- Reason for change: Clutch servo prevents burnout, reduces chassis stress, improves accuracy and lifespan.
Power System
- 2025: 3S1P 18650 lithium pack (11.1 V nominal, 12.6 V max), XL4015 buck converter (5 V/5 A)
- 2026: 3S1P 18650 lithium pack (11.1 V nominal, 12.6 V max), XL4015 buck converter (5 V/5 A), 5 A blade fuse + holder.
- Reason for change: Higher efficiency, modular pack rotation, improved protection. Chassis & Geometry
- 2025: Standard kit wheelbase, basic upper/lower chassis layout.
- 2026:
- 3D-printed ABS chassis (Creality ABS, Prints by Paul).
- Two-plate design with spacers, rib reinforcement for torque resistance.
- Solid axle rear-wheel drive, front-wheel steering.
- Wheelbase: 115 mm; Steering angle: 50°; Turning radius: 40 cm; Wheel width: 25 mm; Diameter: 65 mm; Track width: 140 mm.
- Added airflow channels, air scoop and wing.
- Reason for change: Improved thermal management, rigidity, and durability; added personality and usability features.

## Monthly Logs:

### WRO FE Monthly Log – January

(Research and Slow Start)
Repository & Documentation
- Created a GitHub repository to serve as a centralized backup and version control system for all project files throughout the year.
Power System Development
- Experimented with designing a custom power pack for the RDK X5.
- Ultimately selected a standard configuration: 3× 18650 lithium cells in series, mounted on the designated battery sled.
- Integrated a 5A 5V buck converter and a 5A inline blade fuse to ensure stable voltage regulation and protection for the RDK.

Software & Environment Setup

- Conducted research on ROS2 for potential integration.
- Set up the RDK X5 environment:
- Learned to flash NAND using X Burn and to flash the RDK using RDK Studio.
- Installed essential libraries and tools: matplotlib, numpy, smbus, smbus2, pip, git, VL53L0x, DFRobot I2C-Multiplexer, xfce, TCS34725, I2C-tools.
Hardware Research & Design
- 3D Printing Materials: Researched filament options and selected ABS for chassis printing due to durability and heat resistance.
- Camera Selection: Chose Huskylens V1 for vision capabilities.
- Chassis Improvements compared to 2025 robot:
- Shortened wheelbase.
- Lowered center of gravity by relocating battery pack to the bottom.
- Added a separate layer for I2C lines.
- Aligned time-of-flight sensors above wheels for improved responsiveness.

Thermal Management

- Investigated cooling solutions after observing RDK idle temperatures averaging 60°C, which could interfere with I2C performance.
- Considered adding heatsinks to improve thermal stability.
Progress Challenges
- Development pace slowed due to participation in FTC (FIRST Tech Challenge) during the month, which required time and focus alongside research activities.

### WRO FE Monthly Log – February

(Component Arrival & Early Programming)
Component Acquisition
- Received key hardware parts: TP223 capacitive touch sensor, 5A blade fuse, and heatsinks for thermal management.
Programming & System Familiarization
- Began relearning programming basics on the RDK X5, noting differences in pin control compared to the Raspberry Pi 4.
- Focused on understanding GPIO handling and adapting workflows to the RDK’s architecture.
Chassis Design
- Started designing the robot chassis with a three-layer structure:
- Bottom layer: battery pack and power distribution.
- Middle layer: sensor integration and wiring.
- Upper layer: control board and camera mount. Vision System Exploration
- Borrowed a Huskylens V1 from school.
- Learned basic usage, including how to load and run custom models for object tracking. Component Preparation
- Organized and prepped available components for mounting once the chassis was printed.
- Ensured wiring and sensor placement plans were ready for rapid assembly.

Progress Challenges

- Experienced a two-week delay due to academic test series, temporarily slowing development.

### WRO FE Monthly Log – March

(Chassis Printing & Setup Issues)
Component Acquisition
- Received VL53L1X Time-of-Flight sensor.
- Received ABS filament for chassis printing.
Printing & Fabrication
- Attempted to print the bottom and middle chassis on Mr. Olivier’s printer (Bambulabs P1S) but encountered difficulties with ABS printing.
- Shifted to Paul (Prints by Paul), who used his Creality Ender 3 V2 to print the chassis successfully in ABS, ensuring reliable results.
Software & Environment Challenges
- Encountered issues with library installations, where several packages were installed to the wrong directories.
- Began troubleshooting installation paths to ensure proper integration with the RDK X5 environment.
Progress Challenges
- Development slowed during the first week of March due to academic test series.
- Still waiting on Huskylens V1, which remains backordered in South Africa (estimated 4–6 week wait due to FTC demand).

### WRO FE Monthly Log – April

(Code Re-Evaluation)
Programming Approach
- Took a deliberate step back to re-evaluate coding methodology for the RDK X5.
- Reflected on previous challenges with pin control and library integration, recognizing the need for a more structured and modular approach.
- Began reorganizing code into clearer modules and reusable templates, aiming for improved maintainability and easier troubleshooting.
Focus Areas
- Prioritized pin control consistency, ensuring mappings are documented and verified before implementation.
- Reviewed library installation paths to avoid misplacement issues experienced in March.
- Considered adopting a stepwise testing workflow, where each hardware component (sensors, motors, servos) is validated individually before integration into larger scripts. Progress Challenges
- Slowed forward momentum due to the re-evaluation process, but this was intentional to prevent future inefficiencies.
- Balanced robotics work with ongoing academic responsibilities.

### WRO FE Monthly Log – May

(System Integration & Round 1 Coding)
Major Milestones
- May 2: Achieved full robot movement:
- Steering system operational.
- Motors successfully controlled.
- Colour sensor integrated and functioning.
- May 18: Received and successfully set up the Huskylens V1 camera.
- May 23: Made a major design decision:
- Removed the time-of-flight sensor layer entirely.
- Transitioned to a simplified sensor suite: Huskylens camera, colour sensor, and an additional gyro sensor.

- May 26: Recieved, installed and configured the gyro sensor, ensuring stable readings and integration with the control system.
- May 27: Began developing the full Round 1 code and conducted initial testing. Control Method – Bit-Bashing
- Continued using bit-bashing instead of PWM for servo steering and motor controller ENA pin control.
- Bit-bashing explained:
- A software-driven method of manually toggling GPIO pins to simulate control signals.
- Provides flexibility and direct control without relying on hardware PWM modules.
- Requires precise timing loops in code to maintain accuracy and avoid drift. Round 1 Code Plan
- Robot runs using only the gyro and colour sensor.
- Forward movement until detecting either blue or orange.
- Rotation logic:
- Maintains an array of rotation values for orientation.
- If blue is detected first → assigns counterclockwise array order.
- If orange is detected first → assigns clockwise array order.
- Gyro sensor ensures straight-line stability.
- Colour sensor acts as the trigger for turns:
- When the robot sees the same colour it detected at the start, it executes the corresponding turn.
- Testing results:
- Right turns are smooth and stable.
- Left turns show issues when synchronized with the gyro, requiring further refinement.
Mechanical Adjustments
- Adjusted the steering linkage for proper alignment.
- Added a 2° toe-in angle on the wheels to improve stability and responsiveness.

### WRO FE Monthly Log – June

(Exams & Structural Redesign)
Academic Commitments
- Progress slowed during June due to exam preparation and writing, limiting available time for robotics work.
Coding Progress – Round 1
- Continued refining the Round 1 code.
- Achieved semi-consistent first turns during testing.
- Identified that the gyro sensor required a 10° offset toward the inner wall:
- This adjustment allowed the robot to drive slightly inward.
- Provided a wider turning range, improving reliability of the first manoeuvre. Servo Replacement – June 23
- The original MG996R servo burned out during testing.
- Replaced with the DFRobot 6 kg clutch servo
- Reason for switch:
- Longer lifespan due to clutch mechanism preventing overload.
- Protects chassis by slipping under excessive pressure instead of forcing the steering linkage.
- Improved accuracy and stability, with less twitching compared to the MG996R.
- This change ensures smoother steering and reduces risk of mechanical damage. Mechanical Challenges
- The original under chassis cracked during a test run.
- Highlighted the need for improved structural strength.
Redesign & Reinforcement
- Redesigned the under chassis to include ribs for structural support.
- New design distributes stress more evenly, prevents cracking, and increases durability during repeated test cycles. _________________________________________________________________________________________

### WRO FE Monthly Log – July

(Code Consistency & Hardware Adjustments)
July 1 – Code Consistency & Hardware Adjustments
- Achieved sufficient consistency in Round 1 code execution.
- Modified wheel gear ratios: switched from a speed-oriented ratio to a torque-oriented ratio for better control.
- Adjusted colour sensor positioning: added a 6 mm spacer to lower the sensor, resulting in more accurate readings.
July 2 – Refinement & Sensor Issue
- Focused on improving overall consistency of runs.
- Identified a gyro sensor drifting issue that required correction.

July 3 – Team Sync

- Held a team meeting to review progress and align on outstanding challenges.
- Discussed gyro drift and sensor calibration as next steps.
July 25 – OpenGL Course & Route Mapping
- Began an OpenGL course to integrate advanced visualization and mapping into the robot’s navigation system.
- Goal of OpenGL integration:
- Use gyro + accelerometer data in combination with mat mapping.
- Detect pillar positions and colour IDs using Huskylens.
- Filter sensor data through an ID set, then through a route set.
- Planned workflow:
- Lap 1: Robot maps the board, calibrates speed, and identifies obstacle layout IDs on each side.
- Lap 2 & 3: Robot replays Lap 1 route with improved speed and consistency.

### WRO FE Monthly Log – August

(Regionals, Vision Upgrade & Speed Gains)
August – Regional Competition
- Competed in the regional round of WRO Future Engineers.
- Achieved 2nd place overall, demonstrating strong progress but also exposing areas for improvement.
- Round 1 code was functional but inconsistent, particularly struggling with navigation around extended walls.
Vision System Upgrade
- Decided to replace the colour sensor with a third HuskyLens AI camera facing downward.
- This change provided:
- Higher accuracy in mat colour and feature detection.
- Improved consistency in navigation, especially around extended walls.
- Enabled the robot to take the outer wall route, reducing collisions. Performance Gains
- Speed increased from 17% to 80%, thanks to the HuskyLens upgrade.
- Practice lap times improved by 7 seconds per lap, a major step toward competitive consistency.
Mechanical Adaptation
- Designed and fabricated a custom bracket to mount all three HuskyLens cameras.
- The original two-camera mounting method was insufficient for the tri-camera setup.
- New bracket ensures stable alignment and optimal field of view for both forward and downward cameras.

## Part Purchase page

Part | Website | Photo | Count

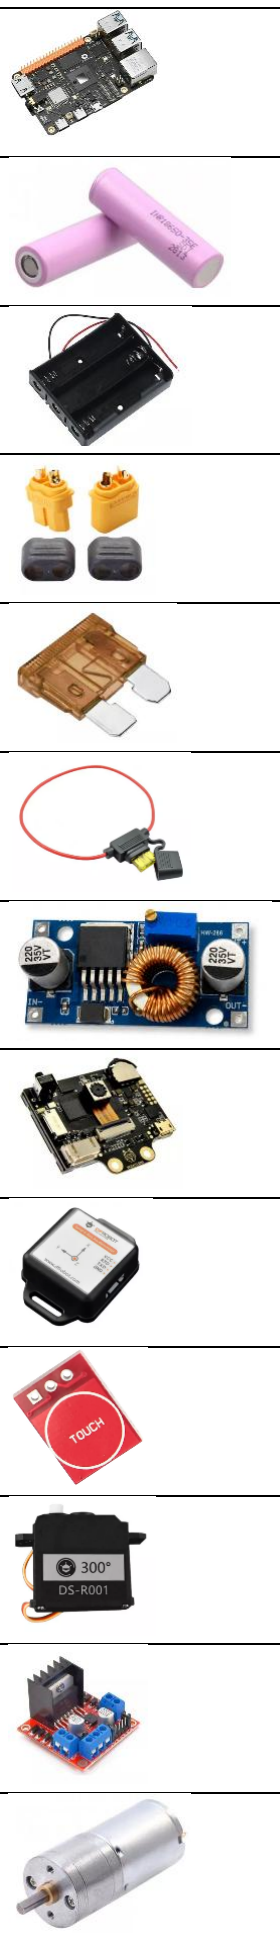
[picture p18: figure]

RDK X5 | Micro Robotics (https://www.robotics.org.za/DFR1239?search=RDK%20X5) | | X 1
18650 Batteries | Micro Robotics (https://www.robotics.org.za/INR18650-35E?search=18650) | | X 15 *
Battery Sled | Micro Robotics (https://www.robotics.org.za/18650-WIRE-3X?search=18650) | | X 3 *
XT60 Connector | Micro Robotics (https://www.robotics.org.za/XT60-KIT?search=XT60) | | X 1
5A Fuse | Micro Robotics (https://www.robotics.org.za/BLADE-5A?search=blade) | | X 1 (10 pack)
Fuse Holder | Micro Robotics (https://www.robotics.org.za/FUSE-INLINE-40A?search=fuse%20holder) | | X 1
Buck Converter | Micro Robotics (https://www.robotics.org.za/XL4015?search=Buck%20regulator) | | X 1
HuskylensV1 | Micro Robotics (https://www.robotics.org.za/SEN0305-S?search=Huskylens) | | X 3
Gyro | Micro Robotics (https://www.robotics.org.za/SEN0386?search=Gyro) | | X 1
Touch Sensor | Micro Robotics (https://www.robotics.org.za/TTP223?search=touch%20sensor) | | X 1 (4 pack)
300° 6Kg Servo | Micro Robotics (https://www.robotics.org.za/SER0057?search=Clutch) | | X 1
L298n | Micro Robotics (https://www.robotics.org.za/L298N?search=l298n) | | X 1
250 RPM DC 12V | Micro Robotics (https://www.robotics.org.za/25GM370-250-12V?search=250%20rpm) | | X 1

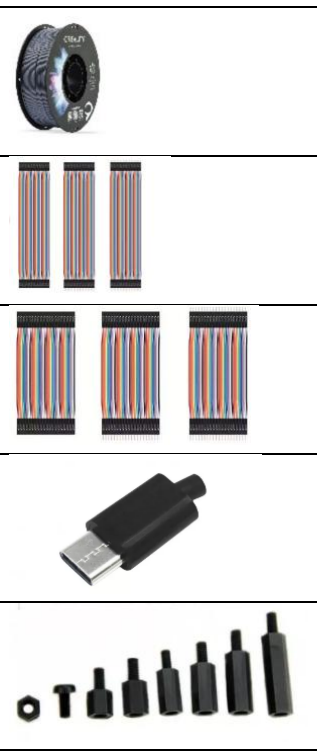
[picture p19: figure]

ABS Filament | takealot.com (https://www.takealot.com/creality-abs-filament-1kg-1-75mm/PLID93516553?colour_variant=Grey+) | X 1
Dupont kit 20 cm | Micro Robotics (https://www.robotics.org.za/RIB-COMBO-20?search=f-f) | X 2
Dupont kit 10 cm | Micro Robotics (https://www.robotics.org.za/RIB-COMBO-10?search=f-f) | X 1
USB-C Male | Micro Robotics (https://www.robotics.org.za/USB-C-CONN?search=Usb%20C&page=4) | X 1 (4 pack)
Nylon Spacer Kit | Micro Robotics (https://www.robotics.org.za/M3-NYL-180-KIT?search=Nylon) | X1

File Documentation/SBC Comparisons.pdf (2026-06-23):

# SBC Comparisons

Board | Pros | Cons
RDK X5 | - Powerful AI acceleration (10TOPS) - Wi-Fi 6 + BT 5.4 - Rich multimedia interfaces - Compact and efficient | - Less community support than Raspberry Pi - Limited documentation for beginners
Raspberry Pi 5 | - Huge community and support - Dual 4K display support - PCIe expansion - Affordable and versatile | - Needs active cooling - Limited AI acceleration compared to Jetson
Jetson Nano | - Excellent for AI and deep learning - CUDA support for TensorFlow, PyTorch - Low power consumption | - No onboard Wi-Fi - Limited general computing power - Fixed 4GB RAM
LattePanda Delta 3 | - Runs full Windows/Linux OS - Arduino-compatible GPIO - Powerful x86 CPU - NVMe and SATA support | - Higher power draw - Larger form factor - GPIO labelling can be confusing
Feature | RDK X5 | Raspberry Pi 5 | Jetson Nano | LattePanda Delta 3
CPU | Octa-Core Cortex-A55 | Quad-core Cortex-A76 (2.4GHz) | Quad-Core Cortex-A57 (1.43GHz) | Intel Celeron N5105 (2.0-2.9GHz)
GPU | 32GFlops GPU 10Tops BPU | Broadcom VideoCore VII | 128 code NVIDIA Maxwell GPU | Intel UHD Graphics
RAM | 4GB/8GB LPDDR4 | 4GB/8GB LPDDR4 | 4GB LPDDR4 | 8GB LPDDR4
Storage | 1GB NAND + TF card slot | microSD + PCIe | microSD+ USB | 64GB eMMC + NVMe/SATA Support
Wireless | Wi-Fi 6 + BT 5.4 | Wi-Fi + BT | No onboard Wi-Fi | Wi-Fi 6 + BT 5.2
USB ports | 4x USB 3.0 | 2x USB 3.0 2x USB 2.0 | 4x USB 3.0 | 3x USB 3.2 USB C
Display output | HDMI MIPI DSI | Dual 4K HDMI | HDMI DP via GPIO | HDMI + DP + eDP
Camera Support | 2 x MIPI CSI | Dual CSI | 1 x MIPI CSI-2 | Arduino Compatible GPIO
Power input | 5V/5A USB-C | 5V/5A USB-C | 5V/4A via micro-USB | 12V DC or USB-C
OS support | Ubuntu 22.04 RDK OS Linux | Raspberry Pi OS Linux | Ubuntu-Based Jetpack | Windows 10/11 Linux

Board | GPIO count and Features
RDK X5 | 28 GPIOs, supports SPI, I2C, I2S, PWM, UART
Raspberry Pi 5 | 40 GPIOs, full support for SPI, I2C, UART, PWM, GPIO interrupts
Jetson Nano | 40 GPIOs, supports I2C, UART, SPI, PWM, I2S
LattePanda Delta 3 | Up to 100 GPIOs via ATmega32U4 (Arduino Leonardo), supports analog/digital I/O
Board | Dimensions (mm) | mm³ | Notes
RDK X5 | 85 × 56 × 20 | 95.2 | Compact and stackable, ideal for embedded robotics and small form factor
Raspberry Pi 5 | 85 × 56 × 17 | 81 | Same footprint as Pi 4; wide accessory compatibility
Jetson Nano | 100 × 80 × 29 | 232 | Larger due to heatsink and carrier board
LattePanda Delta 3 | 125 × 78 × 16 | 156 | Slim but wide, includes Intel CPU and Arduino coprocessor
Best choice | Use case
RDK X5 | Edge AI + Robotics
Raspberry Pi 5 | General Maker Projects
Jetson Nano | AI/ML Projects
LattePanda Delta 3 | Windows + Arduino Combo

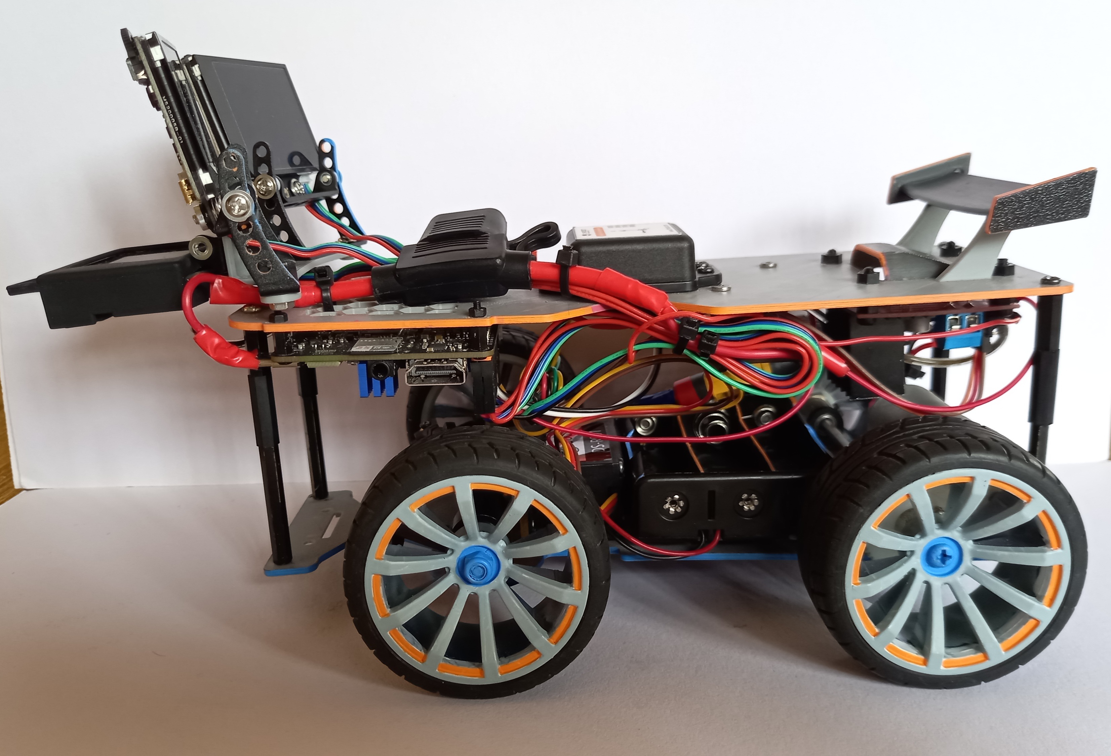
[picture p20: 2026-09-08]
media/Robot photos/Left.jpg

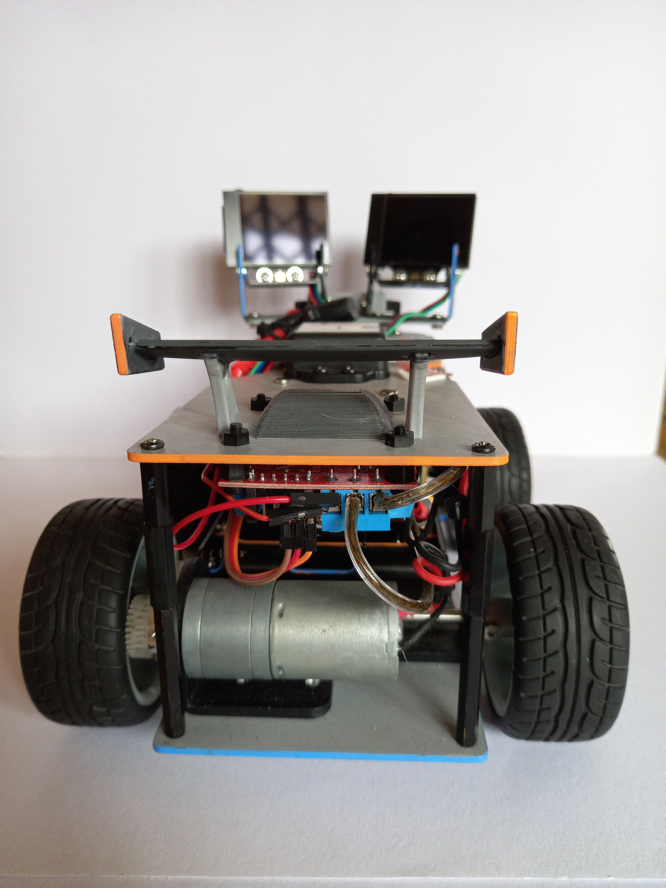
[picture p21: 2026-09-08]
media/Robot photos/Back.jpg

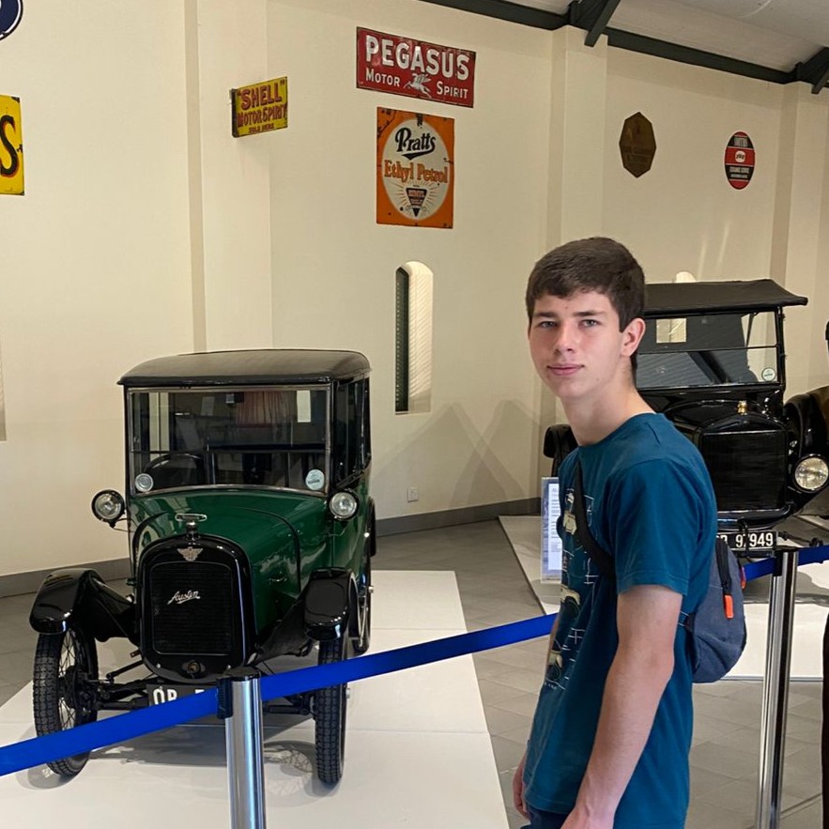
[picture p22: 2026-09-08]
media/Team photos/JadonSteele.jpeg

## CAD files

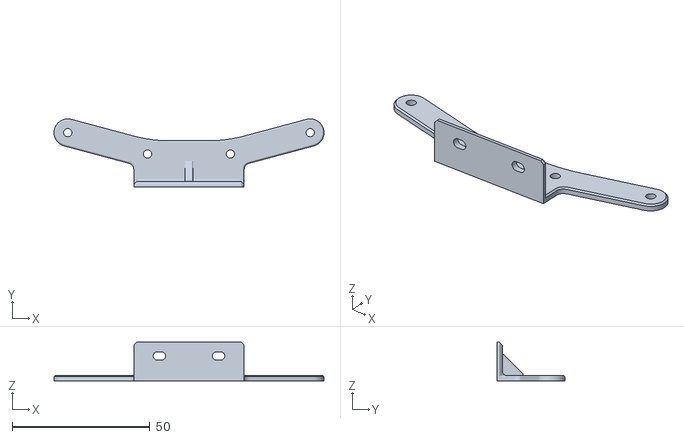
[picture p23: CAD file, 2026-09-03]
models/MountBracket.stl
97.9 x 24.8 x 14.0

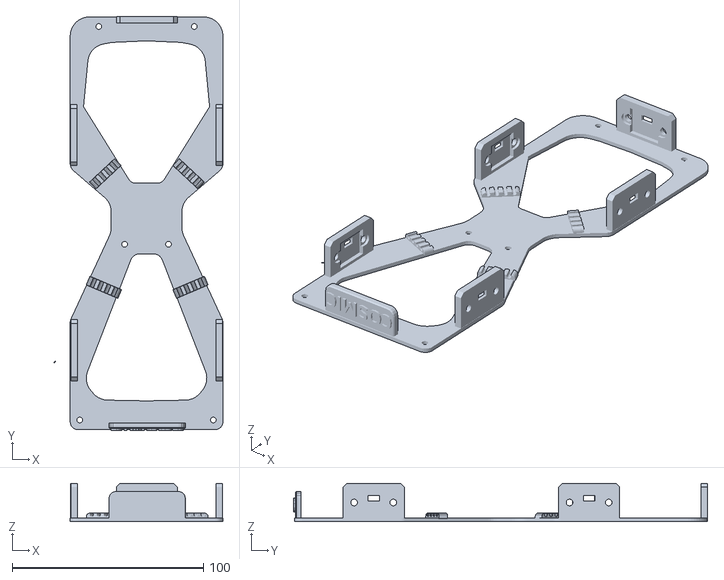
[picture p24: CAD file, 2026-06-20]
models/Removed Files/Middle Chassis.stl
88.4 x 216.8 x 20.0

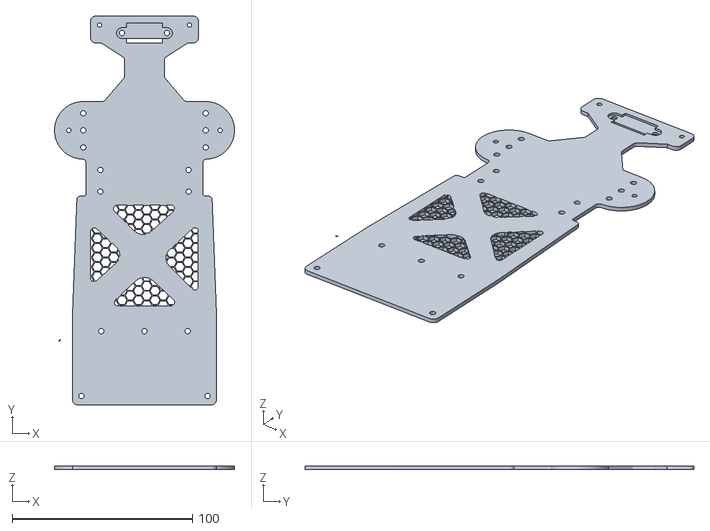
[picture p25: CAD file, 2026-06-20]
models/Bottom No Ribs.stl
100.0 x 216.0 x 5.00

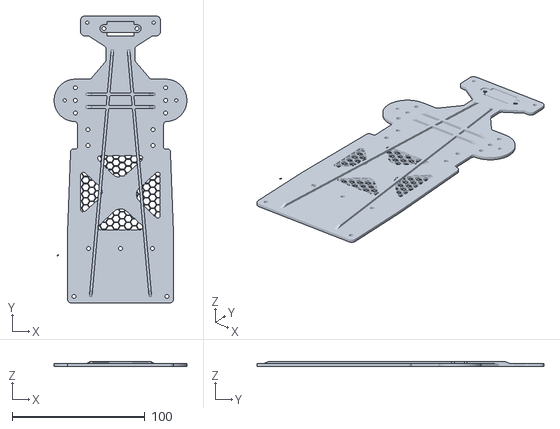
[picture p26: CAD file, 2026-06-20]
models/Bottom Ribs Included.stl
100.0 x 216.0 x 5.00

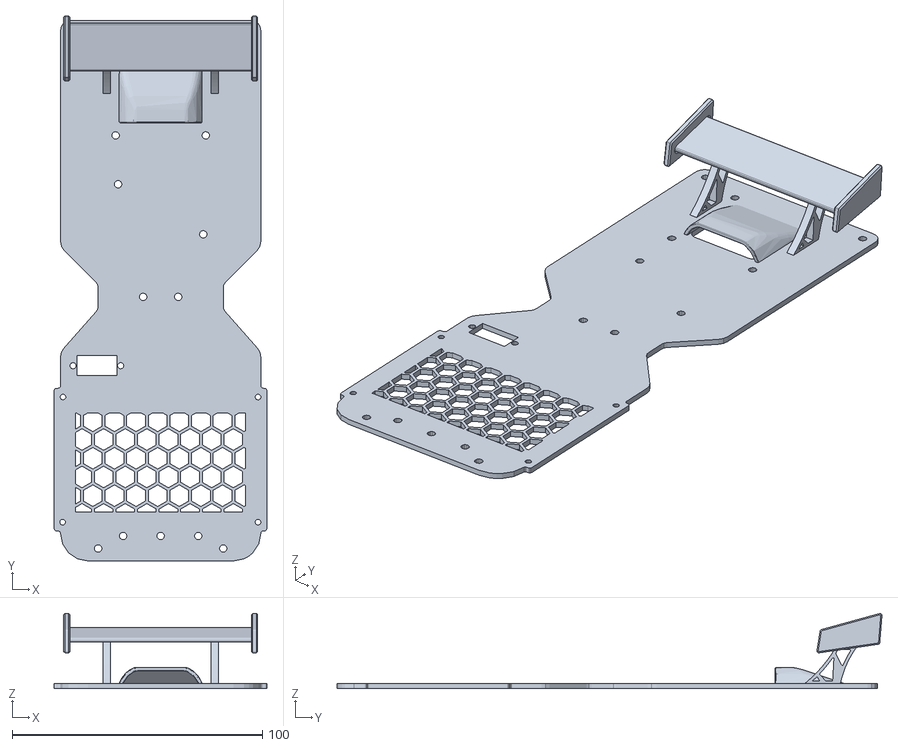
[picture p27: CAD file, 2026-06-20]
models/TopFinal.stl
85.0 x 217.7 x 30.0

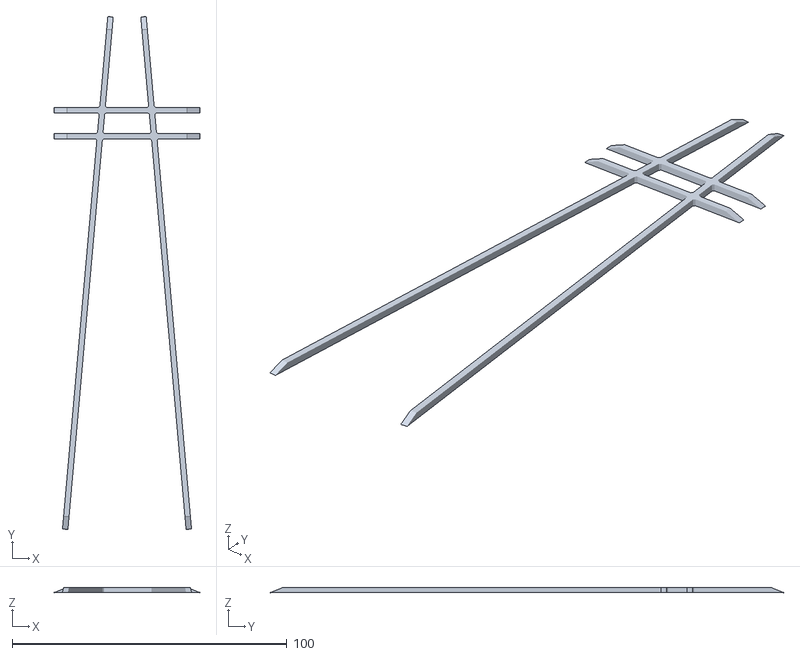
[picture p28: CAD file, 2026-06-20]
models/Ribs Seperate.stl
53.0 x 186.7 x 2.00

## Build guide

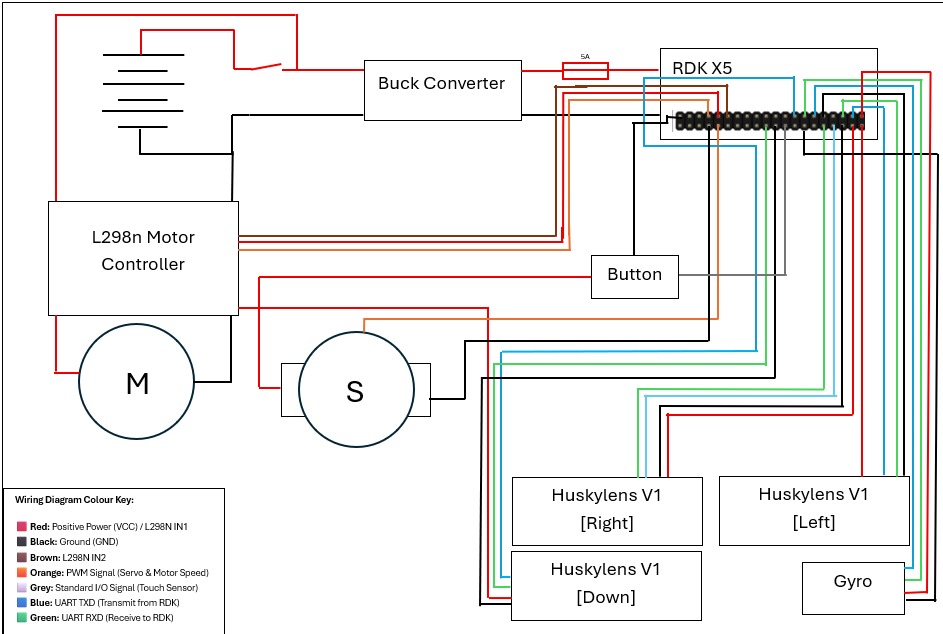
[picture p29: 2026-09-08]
Documentation/WiringDiagram.jpeg

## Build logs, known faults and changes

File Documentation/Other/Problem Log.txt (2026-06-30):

Problem 1:

Robot enters manual turn mode consistently, but does not always exit it even when driving over the exit line.
When the robot does exit the turn mode it gets stuck (It's not getting enough power to the rear wheels to overcome the force of the front wheels being turned)

Testing conditions:

Indoors environment with natural light; well lit.
Robot is running in the anticlockwise direction.

Possible Solutions:

When the robot is stuck after exiting turn mode (don't check if it is stuck) give it a brief pulse of 60% power to give it momentum

Problem 2:

After completing turn 1 when the robot needs to go into manual turn mode for turn 2 it goes a bit too fast
Pulse time for manual turn exit needs to be longer

Testing conditions:

Same conditions as Prior

Possible Solutions:

- When in normal driving mode after exiting manual turn mode add a 0.2 second coast frame every second to make sure it does not drive too fast
- on manual turn exit pulse change power to 70% and double pulse time

Problem 3:

Robot is not reading line for manual turn mode on turn 2. Speed has been reduced by adding in coast period to help the colour sensor

Test conditions:

Indoors environment with natural light; well lit.
Robot is running in the anticlockwise direction.

Possible Solutions:

Tighten line frame detection making the robot need less frames to dictate the colour

Problem 4:

When starting Lap 2 the Robot skips array index 1 and goes directly to index 2

Test conditions:

Indoors environment with natural light; well lit.
Robot is running in the anticlockwise direction.

Problem 5:

With the new colour frame logic, the array index gets updated too frequently

Test conditions:

Indoors environment with natural light; well lit.
Robot is running in the anticlockwise direction.

Problem 6:

Manual turn mode only engages on the first turn, not all of the turns

Test conditions:

Indoors environment with natural light; well lit.
Robot is running in the anticlockwise direction.

Possible Solutions:

Update manual turn mode logic to trigger on all turns

Problem 7:

When starting lap 2 error type: Invalid array index occurs

Test conditions:

Indoors environment with natural light; well lit.
Robot is running in the anticlockwise direction.

Problem 8:

Sometimes the robot drives over the turn indicator lines, but does not read them/react
- Detection frame requirement too long
- Sensor gets varying readings in different light conditions

Test conditions:

Indoors environment with natural light; well lit.
Robot is running in the anticlockwise direction.

Possible Solutions:

- Find a way to get consistent reading regardless of light condition
- Run the colour sensor at a higher polling rate or reduce detection frame requirement

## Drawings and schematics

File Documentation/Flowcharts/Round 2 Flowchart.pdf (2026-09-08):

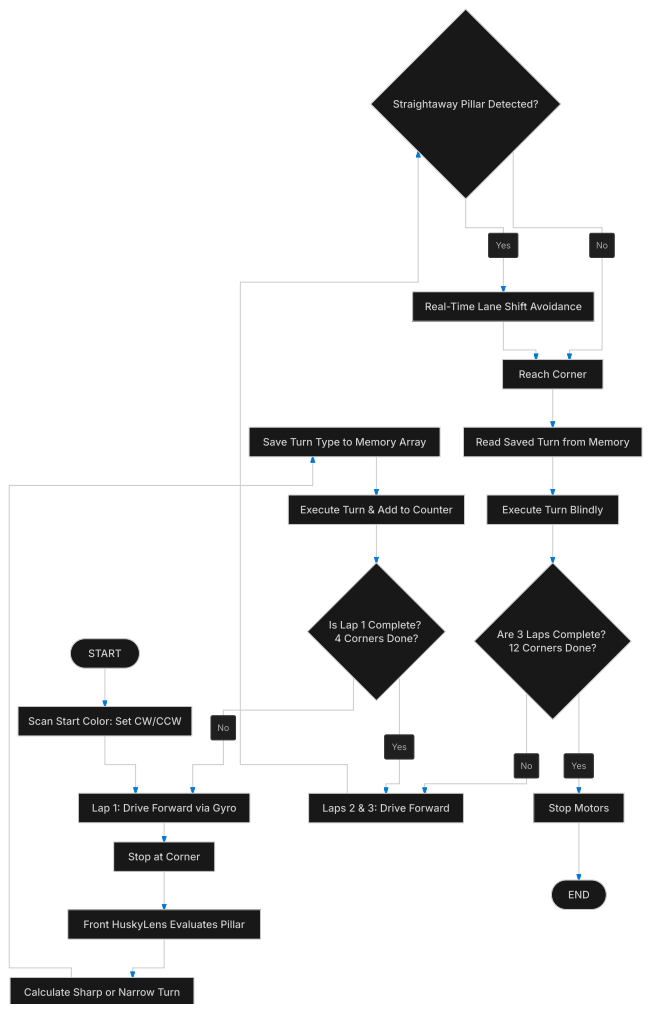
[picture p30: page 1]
Yes; START; Reach Corner; Stop Motors; END

Straightaway Pillar Detected?

Real-Time Lane Shift Avoidance

Save Turn Type to Memory Array

Read Saved Turn from Memory

Execute Turn & Add to Counter

Execute Turn Blindly

Is Lap 1 Complete?
4 Corners Done?

Are 3 Laps Complete?
12 Corners Done?

Scan Start Color: Set CW/CCW

Lap 1: Drive Forward via Gyro

Laps 2 & 3: Drive Forward

Stop at Corner

Front HuskyLens Evaluates Pillar

Calculate Sharp or Narrow Turn

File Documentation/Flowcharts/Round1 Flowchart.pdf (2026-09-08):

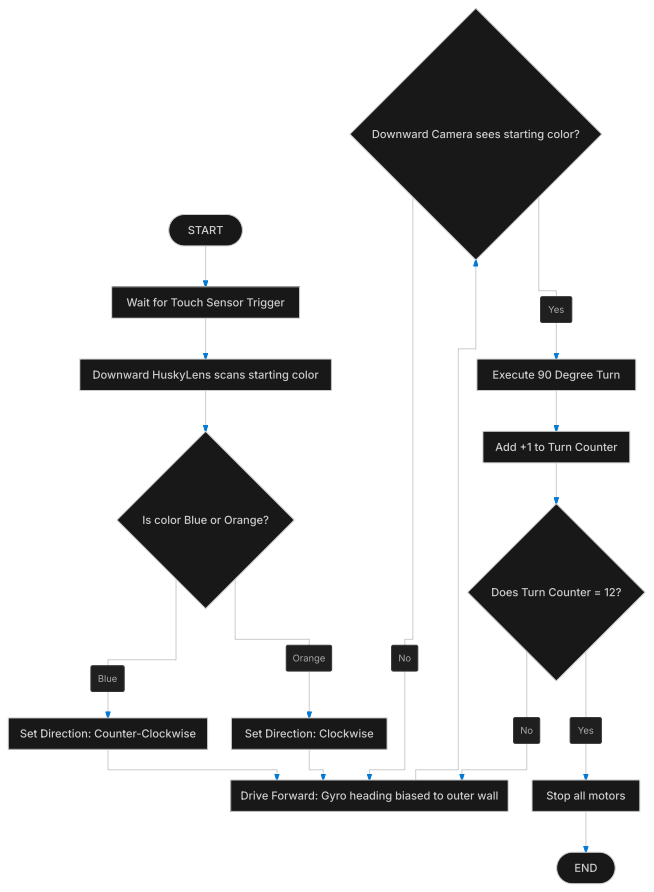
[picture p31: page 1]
Blue; Orange; Yes; START; Set Direction: Counter-Clockwise; Set Direction: Clockwise; END

Downward Camera sees starting color?

Wait for Touch Sensor Trigger

Downward HuskyLens scans starting color

Execute 90 Degree Turn

Add +1 to Turn Counter

Is color Blue or Orange?

Does Turn Counter = 12?

Drive Forward: Gyro heading biased to outer wall

Stop all motors

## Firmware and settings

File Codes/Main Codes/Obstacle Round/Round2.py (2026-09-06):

#!/usr/bin/env python3
# -*- coding: utf-8 -*-
# =============================================================================
# WRO 2026 Future Engineers — Obstacle Challenge
# =============================================================================
"""
===============================================================================
TUNING & TROUBLESHOOTING GUIDE
===============================================================================
1. Servo Twitching / Off-center: Adjust `SERVO_NEUTRAL_MS` (currently 1.4).
   If corners turn too tight one way, adjust `SERVO_OFFSET`.4
2. Gyro Drift: Ensure robot is perfectly still during boot. Adjust
   `ARRAY_CORRECTION` to add/sub degrees per lap to fight mechanical drift.
3. False Pillar Detections: Increase `SIGN_CONFIRM_REQUIRED` (e.g., to 4 out of 5)
   or increase `SIGN_MIN_BOX_WIDTH` so small background objects are ignored.
4. Hitting Pillars: Increase `SIGN_STEER_OFFSET` (currently 25 deg).
5. Parking Overshoot: Lower `PARKING_TURN_IN_S` and `PARKING_STRAIGHTEN_S`.
6. No HuskyLens Data: Check wiring, ensure baud rate is 9600 in HuskyLens menu,
   and confirm the correct `/dev/ttySx` ports are assigned in the Config.
===============================================================================
"""

from __future__ import annotations
import sys
import time
import struct
import threading
import argparse
import math
from enum import Enum, auto
from dataclasses import dataclass
from typing import Dict, List, Optional, Any

# =============================================================================
# 1. CONFIGURATION CONSTANTS
# =============================================================================
SIMULATE: bool = False

# ── GPIO Pins (RDK X5 BOARD numbering) ───
IN1        = 29
IN2        = 31
SERVO_PIN  = 32
ENA        = 33
BUTTON_PIN = 18

# ── Serial Ports ──────────────────────────────────────────────────────────────
GYRO_PORT       = "/dev/ttyS7"
HL_RIGHT_PORT   = "/dev/ttyS1"  # Right forward HuskyLens
HL_DOWN_PORT    = "/dev/ttyS2"  # Down-facing HuskyLens
HL_LEFT_PORT    = "/dev/ttyS3"  # Left forward HuskyLens
HL_BAUD         = 9600
GYRO_BAUD       = 9600

# ── Physical Dimensions ──────────────────────────────────────────────────────
WHEELSPAN_CM      = 11.5
WHEEL_DIAMETER_MM = 65
ROBOT_LENGTH_CM   = 30.0

# ── HuskyLens ID Mapping ─────────────────────────────────────────────────────
HL_DOWN_BLUE_ID   = 1           # Blue on the down camera
HL_DOWN_ORANGE_ID = 2           # Orange on the down camera

HL_FWD_GREEN_ID   = {1, 2, 6}   # Green pillar - pass on the LEFT
HL_FWD_RED_ID     = {3, 4, 5}   # Red pillar - pass on the RIGHT
HL_FWD_PURPLE_ID  = 7           # Purple — parking marker

# Legacy mapping (for Round 1 logic compatibility)
HUSKYLENS_BLUE_ID   = HL_DOWN_BLUE_ID
HUSKYLENS_ORANGE_ID = HL_DOWN_ORANGE_ID

# ── Servo Tuning ─────────────────────────────────────────────────────────────
SERVO_NEUTRAL_MS    = 1.4       # Calibrated neutral
SERVO_TURN_MIN_MS   = 0.9
SERVO_TURN_MAX_MS   = 2.1
SERVO_OFFSET        = 0

# ── Motor / Speed Tuning ─────────────────────────────────────────────────────
NORMAL_SPEED        = 15
CORRECTION_SPEED    = 13
TURN_SPEED          = 25
TURN_CRAWL_SPEED    = 25
EXIT_BURST_POWER    = 20
EXIT_BURST_FRAMES   = 10

MOTOR_PWM_FREQ      = 200
SERVO_PWM_FREQ      = 50

# ── Turn Geometry ────────────────────────────────────────────────────────────
TURN_MAX_ANGLE       = 45
TURN_SETTLE_FRAMES   = 5
TURN_EXIT_DELAY      = 0.0

POST_SEQUENCE_REVERSE_RATIO  = 0.55
POST_SEQUENCE_NEUTRAL_ANGLE  = 0
ARRAY_OFFSET         = -5
ARRAY_CORRECTION     = 0

# ── Color Confirmation ───────────────────────────────────────────────────────
COLOR_READ_THRESHOLD  = 10
BLUE_CONFIRM_THRESHOLD = 5

FIRST_SIDE_MIN = 0.05
FIRST_SIDE_MAX = 10.0

# ── Competition Rules ────────────────────────────────────────────────────────
MAX_LAPS             = 3
MIN_LAPS_FOR_PARKING = 3

# ── Sign Avoidance Tuning ────────────────────────────────────────────────────
SIGN_STEER_OFFSET       = -30.0
SIGN_CONFIRM_SAMPLES    = 5
SIGN_CONFIRM_REQUIRED   = 3
SIGN_MIN_BOX_WIDTH      = 20
SIGN_APPROACH_SPEED     = 20
SIGN_CLEAR_FRAMES       = 8

# ── Pillar Pipeline Tuning ───────────────────────────────────────────────────
MAX_COLOR_SLOTS_PER_CAMERA  = 2       # Max green/red detections kept per camera
CAMERA_FOV_DEG              = 60
CAMERA_OUTWARD_ANGLE_DEG    = 15
LENS_SPACING_MM             = 59
LENS_PIXEL_OFFSET           = 20      # positive means right-camera center is +20 px relative to left-camera center
PILLAR_STEER_MAX_ANGLE      = 30.0    # Max proportional steer from pillar offset
PILLAR_STEER_GAIN           = 0.8     # Pixels → degrees proportional gain
STRICT_CAMERA_SIDE_RULE     = True
INNER_ZONE_HALF_WIDTH       = 40
HALFWAY_RATIO               = 0.25    # fraction of half-frame from center
GREEN_HOLD_S                = 0.12    # seconds to hold straight while waiting
GREEN_SHARPEN               = 1.15
RED_SHARPEN                 = 1.10
PRIMARY_CAMERA_HOLD_S       = 0.10
IMMEDIATE_COLLISION_Y       = 160     # Y-coordinate (0-240) bottom edge emergency threshold
IMMEDIATE_COLLISION_AREA    = 25000   # Bounding box area emergency threshold
MAX_AVOID_ANGLE             = 45       # degrees max gyro offset for avoidance
WIDE_TURN_FORWARD_TIME_S    = 1.75      # Time to drive straight into intersection on a wide turn
SAFE_CLEARANCE_M            = 0.37     # 7cm camera overhang + 20cm wheel gap + 10cm safety margin
DETECTION_DEBOUNCE_S        = 0.15    # 150 ms debounce window
HUSKYLENS_CENTER_X          = 160     # Pixel center of the 320px-wide HuskyLens frame
CENTER_EPSILON_NORM         = 0.15    # normalized offset threshold for "near center"
SIZE_EPSILON                = 100     # Area tie-breaker threshold

# ── Parking Tuning ───────────────────────────────────────────────────────────
PARKING_APPROACH_SPEED    = 25
PARKING_REVERSE_SPEED     = 20
PARKING_TURN_IN_SPEED     = 20
PARKING_TURN_IN_ANGLE     = 40
PARKING_STRAIGHTEN_ANGLE  = -35

PARKING_DRIVE_PAST_S      = 0.6
PARKING_REVERSE_ALIGN_S   = 0.5
PARKING_TURN_IN_S         = 0.8
PARKING_STRAIGHTEN_S      = 0.4
PARKING_FINAL_CREEP_S     = 0.3
PARKING_MARKER_CENTER_X   = 160

def get_estimated_velocity(pwm_speed: int) -> float:
    """
    Maps motor PWM percentage to physical m/s.
    Based on calibration: 80 PWM = 0.92 m/s -> Ratio is 0.0115
    """
    return pwm_speed * 0.0115

# =============================================================================
# 2. MOCK CLASSES (For --simulate flag)
# =============================================================================
class MockGPIO:
    BOARD = "BOARD"
    OUT = "OUT"
    IN = "IN"
    HIGH = "HIGH"
    LOW = "LOW"
    @staticmethod
    def setmode(mode): pass
    @staticmethod
    def setup(pins, mode): pass
    @staticmethod
    def output(pin, state): pass
    @staticmethod
    def input(pin): return MockGPIO.HIGH  # Auto-press button in sim
    @staticmethod
    def setwarnings(flag): pass
    @staticmethod
    def cleanup(): pass

class MockHuskyLensLibrary:
    def __init__(self, interface, port, baud):
        self.port = port
    def algorthim(self, algo): pass
    def requestAll(self):
        return [] # Simulates empty frames by default

class MockSerial:
    def __init__(self, port, baudrate, timeout):
        self.in_waiting = 0
    def read(self, bytes): return b''
    def reset_input_buffer(self): pass

# =============================================================================
# 3. HARDWARE & GPIO SETUP
# =============================================================================
# Global GPIO reference
GPIO = None

def setup_gpio():
    global GPIO
    if SIMULATE:
        GPIO = MockGPIO
    else:
        try:
            import Hobot.GPIO as hobot_gpio  # type: ignore
            GPIO = hobot_gpio
        except ImportError:
            print("WARNING: Hobot.GPIO not found. Using MockGPIO.")
            GPIO = MockGPIO

    GPIO.setwarnings(False)
    GPIO.setmode(GPIO.BOARD)
    GPIO.setup([IN1, IN2, ENA, SERVO_PIN], GPIO.OUT)
    GPIO.setup(BUTTON_PIN, GPIO.IN)

def wait_for_button():
    print("Waiting for button press to start...")
    while GPIO.input(BUTTON_PIN) == GPIO.LOW:
        time.sleep(0.1)
    print("Button pressed — starting up...")


# =============================================================================
# 4. MOVEMENT CLASS (Bit-bang servo/motor)
# =============================================================================
class Movement:
    current_angle         = 0
    offset                = SERVO_OFFSET
    neutral_ms            = SERVO_NEUTRAL_MS
    pulse_ms              = SERVO_NEUTRAL_MS

    _servo_thread_running = False
    _motor_thread_running = False
    _motor_power          = 0

    @staticmethod
    def set_steering_angle(wheel_angle: float, max_angle: float = 40, full_range: bool = False):
        corrected = wheel_angle + Movement.offset
        Movement.current_angle = max(-max_angle, min(max_angle, corrected))
        if full_range:
            Movement.pulse_ms = 1.5 + (Movement.current_angle / max_angle) * 0.5
            Movement.pulse_ms = max(SERVO_TURN_MIN_MS, min(SERVO_TURN_MAX_MS, Movement.pulse_ms))
        else:
            Movement.pulse_ms = Movement.neutral_ms + (Movement.current_angle / max_angle) * 0.5
            Movement.pulse_ms = max(1.0, min(2.0, Movement.pulse_ms))

    @staticmethod
    def _servo_loop():
        while Movement._servo_thread_running:
            high_time  = Movement.pulse_ms / 1000.0
            frame_time = 1.0 / SERVO_PWM_FREQ
            t0 = time.time()
            GPIO.output(SERVO_PIN, GPIO.HIGH)
            time.sleep(high_time)
            GPIO.output(SERVO_PIN, GPIO.LOW)
            elapsed = time.time() - t0
            remainder = frame_time - elapsed
            if remainder > 0:
                time.sleep(remainder)

    @staticmethod
    def start_servo():
        if not Movement._servo_thread_running:
            Movement._servo_thread_running = True
            threading.Thread(target=Movement._servo_loop, daemon=True).start()

    @staticmethod
    def stop_servo():
        Movement._servo_thread_running = False
        GPIO.output(SERVO_PIN, GPIO.LOW)

    @staticmethod
    def set_motor_forward(power: int = 50):
        GPIO.output(IN1, GPIO.LOW)
        GPIO.output(IN2, GPIO.HIGH)
        Movement._motor_power = max(0, min(100, int(power)))

    @staticmethod
    def set_motor_reverse(power: int = 50):
        GPIO.output(IN1, GPIO.HIGH)
        GPIO.output(IN2, GPIO.LOW)
        Movement._motor_power = max(0, min(100, int(power)))

    @staticmethod
    def _motor_loop():
        period = 1.0 / MOTOR_PWM_FREQ
        while Movement._motor_thread_running:
            pwr = Movement._motor_power
            if pwr > 0:
                high_time = (pwr / 100.0) * period
                low_time  = period - high_time
                GPIO.output(ENA, GPIO.HIGH)
                time.sleep(high_time)
                GPIO.output(ENA, GPIO.LOW)
                if low_time > 0:
                    time.sleep(low_time)
            else:
                GPIO.output(ENA, GPIO.LOW)
                time.sleep(period)

    @staticmethod
    def start_motor():
        if not Movement._motor_thread_running:
            GPIO.output(IN1, GPIO.LOW)
            GPIO.output(IN2, GPIO.HIGH)
            Movement._motor_thread_running = True
            threading.Thread(target=Movement._motor_loop, daemon=True).start()

    @staticmethod
    def stop_motor():
        Movement._motor_power = 0
        Movement._motor_thread_running = False
        time.sleep(0.015)
        GPIO.output(ENA, GPIO.LOW)

    @staticmethod
    def brake():
        Movement._motor_power = 0
        Movement._motor_thread_running = False
        time.sleep(0.015)
        GPIO.output(IN1, GPIO.HIGH)
        GPIO.output(IN2, GPIO.HIGH)
        GPIO.output(ENA, GPIO.LOW)

# =============================================================================
# 5. SENSORS (Gyro & HuskyLens)
# =============================================================================
class GyroSensor:
    def __init__(self, port="/dev/ttyS7", baudrate=9600):
        if SIMULATE:
            self.ser = MockSerial(port, baudrate, 0.01)
        else:
            try:
                import serial
                self.ser = serial.Serial(port, baudrate=baudrate, timeout=0.01)
            except Exception as e:
                print(f"WARNING: Gyro init failed on {port}: {e}")
                self.ser = None

        self.base_yaw: Optional[float] = None
        self.yaw: float = 0.0

    def update(self) -> None:
        if self.ser is None: return
        try:
            while self.ser.in_waiting >= 11:
                header = self.ser.read(1)
                if header != b'\x55': continue
                packet_type = self.ser.read(1)
                data = self.ser.read(9)
                if len(data) != 9: continue
                if packet_type == b'\x53':
                    raw_yaw = struct.unpack('<h', data[4:6])[0] / 32768.0 * 180
                    # Only set base_yaw if it is None (this allows calibrate() to reset it)
                    if self.base_yaw is None:
                        self.base_yaw = raw_yaw
                        print(f"Gyro 0-point established at raw yaw: {self.base_yaw:.2f}")
                    
                    self.yaw = raw_yaw - self.base_yaw
                    if self.yaw > 180: self.yaw -= 360
                    elif self.yaw < -180: self.yaw += 360
        except Exception as e:
            pass # Suppressed read error logging to avoid terminal spam

    def calibrate(self, n_samples=50, delay=0.01):
        """Force the gyro to set its current heading as 0."""
        print("Calibrating gyro and establishing 0-point...")
        if self.ser is not None and not SIMULATE:
            self.ser.reset_input_buffer()
        
        # Setting base_yaw to None forces the very next update() to capture it!
        self.base_yaw = None 
        
        for _ in range(n_samples):
            self.update()
            time.sleep(delay)
            
        print(f"Gyro calibrated. Base yaw: {self.base_yaw}  Current: {self.yaw:.2f}°")


@dataclass
class Detection:
    ID: int
    x: int = 0
    y: int = 0
    width: int = 0
    height: int = 0
    cam: str = ""

@dataclass
class PillarContext:
    """Result of the pillar detection pipeline for one control loop frame."""
    closest_pillar: Optional[Detection]   # Highest-priority green/red pillar
    all_color_dets: List[Detection]        # All kept green/red across cameras
    magenta_dets: List[Detection]          # All magenta (uncapped)
    primary_camera: Optional[str]          # "left" / "right" / None

class HuskyLensWrapper:
    def __init__(self, name: str, port: str, baud: int = 9600):
        self.name = name
        self.port = port
        self.is_available = False
        self._hl = None

        if SIMULATE:
            self._hl = MockHuskyLensLibrary("SERIAL", port, baud)
            self.is_available = True
        else:
            try:
                from huskylib import HuskyLensLibrary
                self._hl = HuskyLensLibrary("SERIAL", port, baud)
                self._hl.algorthim("ALGORITHM_COLOR_RECOGNITION")
                self.is_available = True
                print(f"HuskyLens '{name}' initialized on {port}")
            except Exception as e:
                print(f"WARNING: HuskyLens '{name}' init failed on {port}: {e}")

    def request_all(self) -> List[Detection]:
        if not self.is_available or self._hl is None:
            return []
        try:
            results = self._hl.requestAll()
            if not results: return []
            dets = []
            for det in results:
                if hasattr(det, "ID"):
                    dets.append(Detection(
                        ID=det.ID,
                        x=getattr(det, "x", 0),
                        y=getattr(det, "y", 0),
                        width=getattr(det, "width", 0),
                        height=getattr(det, "height", 0),
                        cam=self.name
                    ))
            return dets
        except Exception:
            return []

# =============================================================================
# 6. HELPERS
# =============================================================================
def normalize_angle_error(target: float, current: float) -> float:
    error = target - current
    if error > 180: error -= 360
    elif error < -180: error += 360
    return error

def build_rotation_array_cw(offset=ARRAY_OFFSET) -> list[float]:
    return [0 - offset, -90 - offset, 180 - offset, 90 - offset]

def build_rotation_array_ccw(offset=ARRAY_OFFSET) -> list[float]:
    return [0 + offset, 90 + offset, 180 + offset, -90 + offset]

def _det_area(d: Detection) -> int:
    """Bounding-box area used as proximity metric (larger = closer)."""
    return d.width * d.height

def _det_center_dist(d: Detection) -> float:
    """Horizontal distance from HuskyLens frame center (lower = more centered)."""
    return abs(d.x - HUSKYLENS_CENTER_X)

def _det_sort_key(d: Detection):
    """Sort key: bottom_y descending (closer to bottom of screen), then area descending."""
    # d.y is center, d.height is total height. d.y + d.height/2 is the bottom edge pixel.
    # Higher pixel value = lower on the screen = physically closer to the robot.
    bottom_y = d.y + d.height / 2
    return (-bottom_y, -_det_area(d))

def filter_and_cap(raw_dets: List[Detection]) -> Dict[str, List[Detection]]:
    """
    Per-camera filtering:
    - Separates magenta (ID3) — no cap.
    - Keeps top MAX_COLOR_SLOTS_PER_CAMERA green/red (ID1/ID2) by area,
      filtered by SIGN_MIN_BOX_WIDTH minimum.
    """
    magenta = [d for d in raw_dets if d.ID == HL_FWD_PURPLE_ID]
    color   = [d for d in raw_dets
               if (d.ID in HL_FWD_GREEN_ID or d.ID in HL_FWD_RED_ID) and d.width >= SIGN_MIN_BOX_WIDTH]
    color.sort(key=_det_sort_key)
    # print(f"FILTERED COLORS: {[ (d.ID, d.cam, d.x, d.width) for d in color ]}")
    return {
        "color":   color[:MAX_COLOR_SLOTS_PER_CAMERA],
        "magenta": magenta,
    }

def build_pillar_context(
    left_raw: List[Detection],
    right_raw: List[Detection],
    is_manual_turn: bool,
    turn_direction: Optional[str],   # "left" or "right" or None
) -> PillarContext:
    """
    Full pillar detection pipeline for one control-loop frame.

    - Filters and caps each camera independently.
    - During manual turns, only the primary camera's color detections are used.
    - Outside manual turns, both cameras' detections are merged.
    - Returns a PillarContext with the closest pillar and all relevant detections.
    """
    left_f  = filter_and_cap(left_raw)
    right_f = filter_and_cap(right_raw)

    # Magenta is always merged from both cameras regardless of mode
    all_magenta = left_f["magenta"] + right_f["magenta"]

    primary_camera: Optional[str] = None

    def apply_zone_filter(dets: List[Detection], cam: str) -> List[Detection]:
        if not STRICT_CAMERA_SIDE_RULE:
            return dets
        allowed = []
        for d in dets:
            if cam == "left" and d.ID in HL_FWD_RED_ID:
                if d.x < HUSKYLENS_CENTER_X - INNER_ZONE_HALF_WIDTH:
                    continue  # Ignore red in outer-left band
            if cam == "right" and d.ID in HL_FWD_GREEN_ID:
                if d.x > HUSKYLENS_CENTER_X + INNER_ZONE_HALF_WIDTH:
                    continue  # Ignore green in outer-right band
            allowed.append(d)
        return allowed

    left_allowed = apply_zone_filter(left_f["color"], "left")
    right_allowed = apply_zone_filter(right_f["color"], "right")

    # ALWAYS merge both cameras' capped color detections (Primary camera isolation removed)
    color_dets = left_allowed + right_allowed

    # Sort merged list: closer (larger area) first, center-proximity as tiebreak
    color_dets.sort(key=_det_sort_key)

    closest = color_dets[0] if color_dets else None

    return PillarContext(
        closest_pillar=closest,
        all_color_dets=color_dets,
        magenta_dets=all_magenta,
        primary_camera=None,
    )
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

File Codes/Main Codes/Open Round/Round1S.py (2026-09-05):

#/usr/bin/python3

import Hobot.GPIO as GPIO
import time
import serial
import struct
import smbus2
import threading

# HuskyLens colour recognition (primary colour sensor replacement)
from huskylib import HuskyLensLibrary
# Primary HuskyLens on serial port 2
try:
    hl = HuskyLensLibrary("SERIAL", "/dev/ttyS2", 9600)
    # RESTORED: Deliberate typo because the HuskyLens library spells it this way!
    hl.algorthim("ALGORITHM_COLOR_RECOGNITION")
    print("HuskyLens initialized on /dev/ttyS2")
except Exception as _e:
    hl = None
    print("HuskyLens init failed or not present:", _e)

# -----------------------------
# GPIO Setup
# -----------------------------
GPIO.setwarnings(False)
GPIO.setmode(GPIO.BOARD)

IN1 = 29
IN2 = 31
ServoPin = 32
ENA = 33
ButtonPin = 18
GPIO.setup([IN1, IN2, ENA, ServoPin], GPIO.OUT)
GPIO.setup(ButtonPin, GPIO.IN)

# -----------------------------
# Movement Class
# -----------------------------
class Movement:
    current_angle         = 0
    offset                = 0      # trim ±2–3 if one direction turns tighter/wider than the other
    neutral_ms            = 1.4
    # Initialise pulse_ms to neutral, NOT 1.5 — prevents the servo from
    # snapping right the moment the servo thread starts.
    pulse_ms              = 1.4

    _servo_thread_running = False
    _motor_thread_running = False
    _motor_power          = 0      # shared duty-cycle value, written by main thread,
                                   # read by motor thread — range 0–100

    # ── Servo bit-bang ────────────────────────────────────────────────────────
    @staticmethod
    def set_steering_angle(wheel_angle, max_angle=40, full_range=False):
        """
        full_range=False  normal driving: centres on calibrated neutral_ms (1.4 ms).
        full_range=True   turn mode:      centres at 1.5 ms so ±max_angle maps
                          across the widest safe physical range (SERVO_TURN_MIN_MS
                          to SERVO_TURN_MAX_MS).
        """
        corrected = wheel_angle + Movement.offset
        Movement.current_angle = max(-max_angle, min(max_angle, corrected))

        if full_range:
            Movement.pulse_ms = 1.5 + (Movement.current_angle / max_angle) * 0.5
            Movement.pulse_ms = max(SERVO_TURN_MIN_MS, min(SERVO_TURN_MAX_MS, Movement.pulse_ms))
        else:
            Movement.pulse_ms = Movement.neutral_ms + (Movement.current_angle / max_angle) * 0.5
            Movement.pulse_ms = max(1.0, min(2.0, Movement.pulse_ms))

    @staticmethod
    def _servo_loop():
        """Bit-bang a 50 Hz servo signal.  Runs in its own daemon thread."""
        while Movement._servo_thread_running:
            high_time  = Movement.pulse_ms / 1000.0
            frame_time = 0.02          # 50 Hz → 20 ms frame
            t0 = time.time()
            GPIO.output(ServoPin, GPIO.HIGH)
            time.sleep(high_time)
            GPIO.output(ServoPin, GPIO.LOW)
            elapsed = time.time() - t0
            remainder = frame_time - elapsed
            if remainder > 0:
                time.sleep(remainder)

    @staticmethod
    def start_servo():
        if not Movement._servo_thread_running:
            Movement._servo_thread_running = True
            threading.Thread(target=Movement._servo_loop, daemon=True).start()

    @staticmethod
    def stop_servo():
        Movement._servo_thread_running = False
        GPIO.output(ServoPin, GPIO.LOW)

    # ── Motor bit-bang ────────────────────────────────────────────────────────
    @staticmethod
    def set_motor_forward(power=50):
        """
        Set direction to forward and update the target duty cycle.
        The motor thread reads _motor_power and handles all PWM timing —
        this call returns immediately so it never blocks the main loop.
        """
        GPIO.output(IN1, GPIO.LOW)
        GPIO.output(IN2, GPIO.HIGH)
        Movement._motor_power = max(0, min(100, int(power)))

    @staticmethod
    def _motor_loop():
        """
        Bit-bang ~200 Hz PWM on ENA in its own daemon thread.
        Completely decoupled from the main loop so timing is consistent
        regardless of gyro reads, colour reads, or print statements.
        """
        freq   = 200
        period = 1.0 / freq    # 5 ms per PWM cycle
        while Movement._motor_thread_running:
            pwr = Movement._motor_power
            if pwr > 0:
                high_time = (pwr / 100.0) * period
                low_time  = period - high_time
                GPIO.output(ENA, GPIO.HIGH)
                time.sleep(high_time)
                GPIO.output(ENA, GPIO.LOW)
                if low_time > 0:
                    time.sleep(low_time)
            else:
                # Power is zero — keep ENA low for the full period
                GPIO.output(ENA, GPIO.LOW)
                time.sleep(period)

    @staticmethod
    def start_motor():
        if not Movement._motor_thread_running:
            # Direction defaults to forward; caller sets it before the first
            # set_motor_forward() if needed.
            GPIO.output(IN1, GPIO.LOW)
            GPIO.output(IN2, GPIO.HIGH)
            Movement._motor_thread_running = True
            threading.Thread(target=Movement._motor_loop, daemon=True).start()

    @staticmethod
    def stop_motor():
        """Stop the motor thread and ensure ENA is left low."""
        Movement._motor_power = 0
        Movement._motor_thread_running = False
        time.sleep(0.015)          # allow thread to finish its current pulse
        GPIO.output(ENA, GPIO.LOW)

    @staticmethod
    def brake():
        """Hard brake: short IN1/IN2, kill ENA, stop motor thread."""
        Movement._motor_power = 0
        Movement._motor_thread_running = False
        time.sleep(0.015)          # allow thread to finish its current pulse
        GPIO.output(IN1, GPIO.HIGH)
        GPIO.output(IN2, GPIO.HIGH)
        GPIO.output(ENA, GPIO.LOW)

# -----------------------------
# Gyro Sensor Class
# -----------------------------
class GyroSensor:
    def __init__(self):
        self.ser = serial.Serial('/dev/ttyS7', baudrate=9600, timeout=0.01)
        self.base_yaw = None
        self.yaw = 0.0

    def update(self):
        while self.ser.in_waiting >= 11:
            header = self.ser.read(1)
            if header != b'\x55':
                continue
            packet_type = self.ser.read(1)
            data = self.ser.read(9)
            if len(data) != 9:
                continue
            if packet_type == b'\x53':
                raw_yaw = struct.unpack('<h', data[4:6])[0] / 32768.0 * 180
                if self.base_yaw is None:
                    self.base_yaw = raw_yaw
                self.yaw = raw_yaw - self.base_yaw
                if self.yaw > 180:
                    self.yaw -= 360
                elif self.yaw < -180:
                    self.yaw += 360
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

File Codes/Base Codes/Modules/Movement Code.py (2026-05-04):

import Hobot.GPIO as GPIO
import time

# -----------------------------
# General Setup
# -----------------------------
GPIO.setwarnings(False)
GPIO.setmode(GPIO.BOARD)

# -----------------------------
# Pins
# -----------------------------
IN1 = 29
IN2 = 31
LEDPin = 37
ServoPin = 32
ENA = 33
ButtonPin = 18

# -----------------------------
# GPIO Setup
# -----------------------------
outputPins = [IN1, IN2, LEDPin, ENA, ServoPin]
GPIO.setup(outputPins, GPIO.OUT)
GPIO.output(LEDPin, GPIO.HIGH)
GPIO.setup(ButtonPin, GPIO.IN)

# -----------------------------
# Confirm channels
# -----------------------------
print("GPIO29: ", GPIO.gpio_function(29))
print("GPIO31: ", GPIO.gpio_function(31))
print("GPIO37: ", GPIO.gpio_function(37))
print("GPIO32: ", GPIO.gpio_function(32))
print("GPIO33: ", GPIO.gpio_function(33))
print("GPIO18: ", GPIO.gpio_function(18))

# -----------------------------
# Movement Class
# -----------------------------
class Movement:
    @staticmethod    
    def _motor_pwm(power, freq, duration=None):
        period = 1.0 / freq
        high_time = (power / 100.0) * period
        low_time = period - high_time
        
        if duration is None:
            try:
                while True:
                    GPIO.output(ENA, GPIO.HIGH)
                    time.sleep(high_time)
                    GPIO.output(ENA, GPIO.LOW)
                    time.sleep(low_time)
            except KeyboardInterrupt:
                Movement.coast()
        else:
            end_time = time.time() + duration
            while time.time() < end_time:
                GPIO.output(ENA, GPIO.HIGH)
                time.sleep(high_time)
                GPIO.output(ENA, GPIO.LOW)
                time.sleep(low_time)
            
    @staticmethod
    def forward(power, duration, freq=500):
        GPIO.output(IN1, GPIO.LOW)
        GPIO.output(IN2, GPIO.HIGH)
        Movement._motor_pwm(power, freq, duration)

    @staticmethod
    def backward(power, duration, freq=500):
        GPIO.output(IN1, GPIO.HIGH)
        GPIO.output(IN2, GPIO.LOW)
        Movement._motor_pwm(power, freq, duration)

    @staticmethod
    def continuous_forward(power, freq=500):
        GPIO.output(IN1, GPIO.LOW)
        GPIO.output(IN2, GPIO.HIGH)
        Movement._motor_pwm(power, freq)
    
    @staticmethod
    def continuous_backward(power, freq=500):
        GPIO.output(IN1, GPIO.HIGH)
        GPIO.output(IN2, GPIO.LOW)
        Movement._motor_pwm(power, freq)
            
    @staticmethod
    def coast():
        GPIO.output(IN1, GPIO.LOW)
        GPIO.output(IN2, GPIO.LOW)
        GPIO.output(ENA, GPIO.LOW)

    @staticmethod
    def brake():
        GPIO.output(IN1, GPIO.HIGH)
        GPIO.output(IN2, GPIO.HIGH)
        GPIO.output(ENA, GPIO.LOW)

    @staticmethod
    def servo_angle(angle):
        neutral_ms = 1.0
        left_ms = neutral_ms - 0.65   
        right_ms = neutral_ms + 0.65  
        pulse_ms = left_ms + ((angle - 35) / (145 - 35)) * (right_ms - left_ms)

        period_ms = 20.0
        high_time = pulse_ms / 1000.0
        low_time = (period_ms / 1000.0) - high_time

        for i in range(50):
            GPIO.output(ServoPin, GPIO.HIGH)
            time.sleep(high_time)
            GPIO.output(ServoPin, GPIO.LOW)
            time.sleep(low_time)
    
    @staticmethod
    def drive(power, duration=None, angle=90, freq=500):
        Movement.servo_angle(angle)
        if power >= 0:
            GPIO.output(IN1, GPIO.LOW)
            GPIO.output(IN2, GPIO.HIGH)
        else:
            GPIO.output(IN1, GPIO.HIGH)
            GPIO.output(IN2, GPIO.LOW)
            power = abs(power)
        Movement._motor_pwm(power, freq, duration)

# -----------------------------
# Main Program
# -----------------------------
try:
    print("Waiting for button press to start...")
    GPIO.wait_for_edge(ButtonPin, GPIO.RISING)
    print("Button pressed, Starting code.")

except KeyboardInterrupt:
    print("Interrupted by user")

finally:
    GPIO.cleanup()
    print("GPIO cleanup complete.")

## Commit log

2026-05-14 Showcase code
    Showcase code was made to demonstrate the movement of the robot and to try and get the robot to turn 90 degrees manually in case anything failed while it was busy with a run to have a manual override
    [showcase.py]
2026-05-27 Round 1 code, using Gyro
2026-06-16 Fixed Steering and Gyro
    [Round1.py]
2026-06-17 Round1 - Bug Fixes
    [Round1.py]
2026-06-20 Additional Media Uploads
    Photos and Videos taken during the process of getting the robot to work
    [Bottom No Ribs.stl, Bottom Ribs Included.stl, Bottom Ribs.stl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]
2026-06-23 Updating Repository with SBC comparison Document
    [Ribs Seperate.stl]
2026-06-24 Updated main code to accomodate new servo
    Our original servo burned out so we switched to a DFRobot 300 degree 6KG Clutch servo
    [Round1.py, ServoTest.py]
2026-06-26 Fixing turns for new servo
    [Round1.py, ServoTest.py, colour readings.py]
2026-06-29 Bug Fixes - Turn 2
    Working code where robot consistently gets to turn 2
    [Round1.py]
2026-06-29 Round 1 Code 06/29
    Round 1 code stopping point for 06/29 and added in problem log to keep track of problems encountered in the process of debugging
    [Round1.py]
2026-06-30 Alternate + bug fixes
    Tried a different method of completing round 1 and sorted out bug fixes
    [Round1.py]
2026-07-01 3 laps
    Got the robot to run 3 laps on round 1 Relatively consistently. Just need to sort out Gyro Drift
    [Round1.py]
2026-07-14 Cleanup of round 2 framework
2026-08-01 Round 1 code calibration
2026-08-08 Round 1 code final bugs
    [Round1.py]
2026-08-31 Round 1 Huskylens
    Replaced the usage of the colour sensor with the Huskylens V1
    [Round1.py, Round1Secondary.py]
2026-09-03 Round 2 Creation/Starting code
    [MountBracket.stl]
2026-09-07 Readme Update
    Just need to create flowchart and wiring diagram
